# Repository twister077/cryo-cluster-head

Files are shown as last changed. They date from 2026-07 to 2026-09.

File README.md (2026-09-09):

# CryoClusterHead — Open-Source Cluster Headache Detection & Relief System

> **⚠ Experimental Research Project.** Not a certified medical product. Use at your own risk.

## Overview

Cluster headaches are among the most excruciatingly painful conditions known. This project explores an open-source hardware and software approach to **early detection of cluster headache flare-ups** using continuous skin temperature monitoring. 

By tracking rapid localized temperature changes ($\Delta T/\Delta t$) at the temple/neck area during the prodromal phase, our goal is to provide an early warning notification **minutes before peak pain hits**, allowing for timely intervention (such as cold therapy or medication).

---

## Current Focus & Development Tracks

The repository is structured into two main tracks:

### 🚀 Track A — Non-BLE Test Patch (Active Focus)
- **Hardware:** Miniature round PCB (`cryo-alert-patch/hardware/pcb/`) featuring **STM32L011** MCU + **TMP117** high-precision temperature sensor (B.Cu contact), CR1220 battery, piezo buzzer, LED, and tactile switch (`SW1`).
- **Firmware (`cryo-alert-patch/firmware-stm32/`)**: PlatformIO / STM32Cube HAL implementation featuring TMP117 I2C driver, ADC battery monitoring, alert state machine, and robust **$\Delta T/\Delta t$ flare-up detection** (validated with a host-side unit test suite).

### 📡 Track B — BLE & Companion Ecosystem (Planned / Later)
- **Hardware & Software:** nRF52832-based variants, `cryo-active-cooler/`, and `cryo-mobile-app/` (Flutter + Rust core).
- **Status:** Documented for future integration after Track A hardware testing and validation are completed.

---

## Community & Collaboration Welcome!

Building open-source medical/health hardware and embedded firmware is a massive undertaking for a single developer. **I cannot do this alone!** 

Whether you are an embedded firmware engineer, PCB designer (KiCad), mobile app developer, or a fellow cluster headache sufferer / researcher wanting to share insights — **your input, contributions, and feedback are immensely welcome.**

- **Open Issues & PRs:** Feel free to open issues or submit pull requests directly in this repository.
- **Discussions / Contact:** Reach out via GitHub issues or discussions to collaborate.

---

## Repository Structure

- `cryo-alert-patch/` — Hardware schematics, Gerber files, and firmware (`firmware-stm32/` for STM32 test track, `firmware-zephyr-ble/` for Zephyr/BLE).
- `cryo-mobile-app/` — Flutter companion app with Rust core for real-time $\Delta T/\Delta t$ analysis *(Track B)*.
- `cryo-active-cooler/` — Optional Peltier active cooling module concept *(Track B)*.
- `plan.md` — Detailed multi-phase project roadmap.

## License

- **Firmware:** MIT
- **Hardware:** CERN-OHL-S-2.0

---

## Contributors & AI Co-Developer

- **Twister077** — Project Initiator, Lead Concept & Hardware Architect.
- **Hermes Agent (Nous Research)** — AI Co-Developer & Engineering Assistant (assisted with KiCad schematic reconstruction, DRC/ERC validation, Gerber preparation, and STM32 PlatformIO firmware/testing).

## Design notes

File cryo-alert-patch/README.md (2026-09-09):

# Cryo Alert Patch

> Part of the [CryoClusterHead](../README.md) system — open-source cluster headache detection and relief.

**Temperature sensor patch for early detection of cluster headache flare-ups.**

This repo contains two hardware/firmware tracks:

---

## Track A — Non-BLE test patch (current, active)

A simplified, standalone test version of the patch with **no Bluetooth**. Used to validate the core hypothesis: *Can skin temperature monitoring reliably detect cluster headache prodromes?*

**Hardware:** STM32L011 MCU + TMP117 precision temperature sensor + piezo buzzer + LED + button (all on a 34mm round PCB).

### PCB Renders (Track A)

| Isometric View | Top View (Components) | Bottom View (Skin Contact / TMP117) |
|:---:|:---:|:---:|
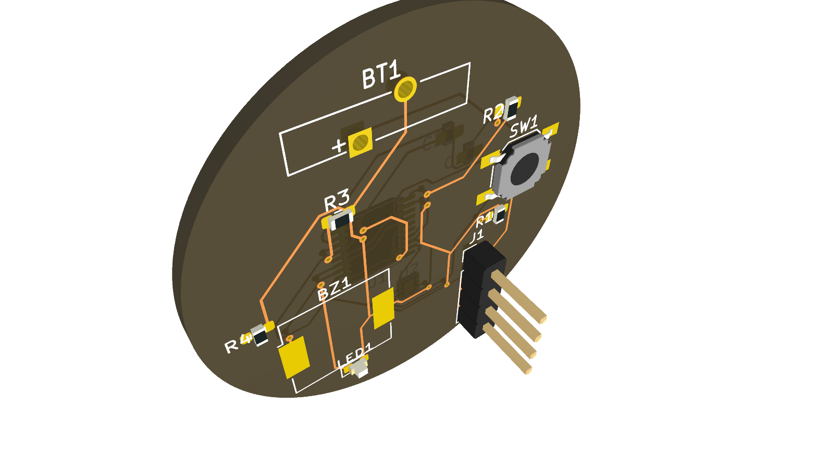
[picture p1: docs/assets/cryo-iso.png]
Isometric
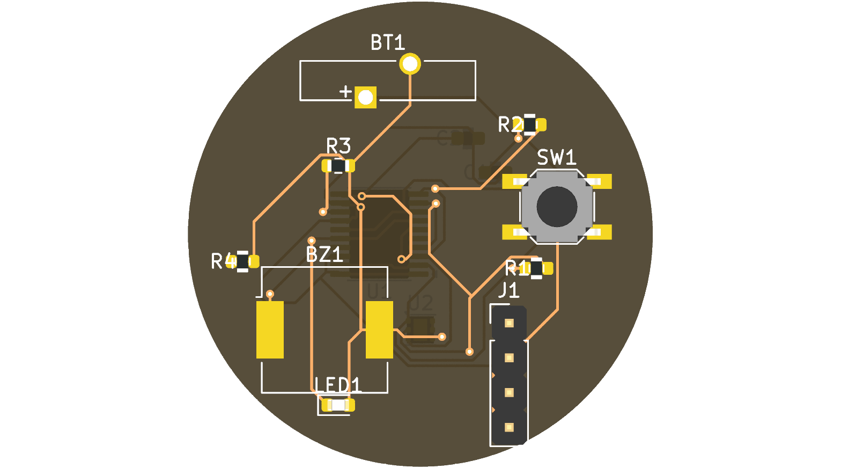
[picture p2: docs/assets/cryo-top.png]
Top
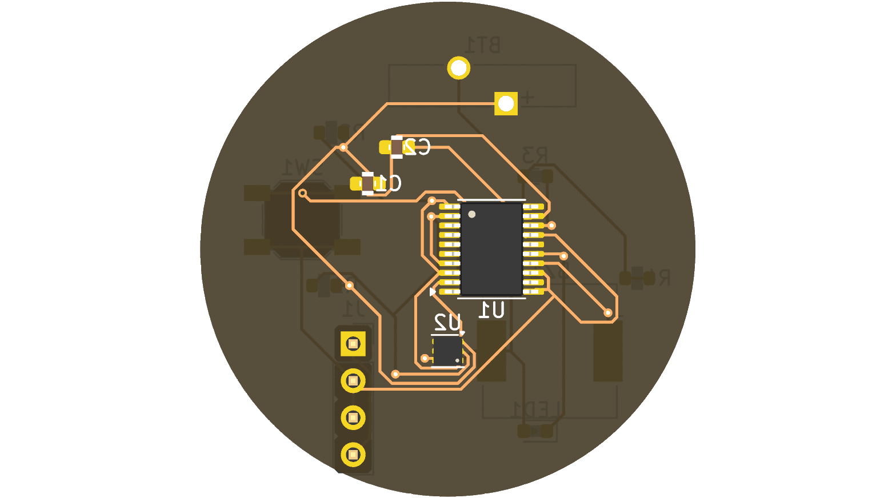
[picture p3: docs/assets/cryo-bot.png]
Bottom
|  |  |  |

**Firmware:** `firmware-stm32/` — PlatformIO + STM32Cube HAL.

| Feature | Status | Description |
|---|---|---|
| TMP117 I2C driver | ✅ | Reads skin temperature via sensor on B.Cu (direct skin contact) |
| ADC battery monitoring | ✅ | CR1220 voltage via VBAT_SENSE pin |
| dT/dt rate-of-change detection | ✅ | Rolling window, spike confirmed over consecutive high-rate samples |
| LED/buzzer alert state machine | ✅ | Normal / Warning / Critical / Muted states |
| Button debounce + snooze | ✅ | Press to silence alarm for 30 seconds |
| Low-power sleep | ✅ | Sleep mode (WFI) between measurements to extend battery life |
| Host-side unit tests | ✅ | 10/10 pass via `test/run_tests.sh` |
| BLE / phone connection | ⬜ | Not in scope for this track — see Track B |

### Quick start

```bash
cd firmware-stm32

# Run host-side unit tests (no hardware needed)
test/run_tests.sh

# Build firmware
pio run

# Flash via SWD (ST-Link / J-Link connected to J1 POGO pads)
pio run -t upload
```

See [`firmware-stm32/BUILD.md`](firmware-stm32/BUILD.md) for full build, flash, and pin mapping details.

---

## Track B — BLE version (planned, later phase)

The full Bluetooth Low Energy version with phone connectivity. This is the production target — the patch communicates with the [Cryo Mobile App](../cryo-mobile-app) for live dT/dt monitoring, push notifications, and data logging.

**Hardware:** nRF52832 MCU + MAX30205 clinical-grade temperature sensor.

**Firmware:** `firmware/` (Zephyr RTOS, Nordic SDK).

| Feature | Status | Description |
|---|---|---|
| BLE temperature broadcast | ⬜ | Advertise temperature via BLE advertising packets |
| MAX30205 sensor | ⬜ | Clinical-grade temperature sensing |
| Mobile app integration | ⬜ | Connect to Cryo Mobile App for live monitoring |
| Data logging | ⬜ | Store temperature history for later analysis |

> **Note:** The nRF52832 PCB design has known issues (pin mapping errors, missing crystal/antenna) that need to be resolved before Track B can be built. See the [project plan](../plan.md) for details.

---

## Components

| Component | Repository | Description |
|---|---|---|
| Alert Patch | `cryo-alert-patch` | This repo — firmware + hardware |
| Mobile App | `cryo-mobile-app` | Flutter + Rust Core — dT/dt detection |
| Active Cooler | `cryo-active-cooler` | Optional add-on — Peltier cooling module |

## License

- **Firmware:** MIT
- **Hardware:** CERN-OHL-S-2.0

> **⚠ Experimental device. Not a certified medical product. Use at your own risk.**

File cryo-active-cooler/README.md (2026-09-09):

# Cryo Active Cooler

> Part of the [CryoClusterHead](../README.md) system — open-source cluster headache detection and relief.

**Smart Peltier cooling module with triple-redundant temperature safety.**

An optional add-on for the CryoClusterHead system. When a flare-up is detected, this headband-mounted module provides active cooling directly to the painful area.

> **Note on Project Status:** This module (along with BLE features) belongs to **Track B (Future / BLE Version)**. The current active development track is **Track A (Non-BLE Test Patch)** using the STM32L011 + TMP117.

## Features

Unlike simple Peltier drivers, the Active Cooler is a safety-first intelligent module:

- **3 cooling levels** — automatically selected based on flare-up severity
- **Triple temp voting** — reads temperature from 3 independent sources for fail-safe operation
- **15-minute max timer** — hard limit prevents over-cooling
- **Auto step-down** — gradually reduces cooling as temperature normalizes
- **No phone required** — can read the Alert Patch directly via BLE *(Track B)*

## Temperature Safety Voting

```
┌──────────────────┐
│ Patch BLE        │──┐
│ (via phone relay)│  │
└──────────────────┘  │
                      ├──► Firmware majority vote
┌──────────────────┐  │    (≥2 agree → use that temp)
│ Patch BLE        │──┘
│ (direct)         │
└──────────────────┘
┌──────────────────┐
│ Local sensor     │
│ (MAX30205 on     │
│  cold side)      │
└──────────────────┘
```

If fewer than 2 sources agree → **safe shutdown** (Level 0).

## Cooling Levels

| Level | Condition | PWM | Description |
|---|---|-----|---|
| 0 | Normal temp / safety fault | 0% | Off |
| 1 | Mild rise (+0.3–0.8°C) | 33% | Gentle cooling |
| 2 | Moderate rise (+0.8–1.5°C) | 66% | Active cooling |
| 3 | Strong rise (>1.5°C) | 100% | Max cooling |

- Each level auto-advances based on current temperature
- Auto step-down as temp drops
- Hard cutoff after 15 minutes regardless of level

## Quick Start *(Track B - Planned)*

```bash
cd firmware
west init -l .
west update
west build -b nrf52832dk_nrf52832 .
west flash
```

## License

- **Firmware:** MIT
- **Hardware:** CERN-OHL-S-2.0

> **⚠ Experimental device. Not a certified medical product. Use at your own risk.**

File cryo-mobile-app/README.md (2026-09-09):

# Cryo Mobile App

> Part of the [CryoClusterHead](../README.md) system — open-source cluster headache detection and relief.

**Flutter + Rust app for real-time temperature monitoring and flare-up detection.**

Pairs with the [Cryo Alert Patch](../cryo-alert-patch) via BLE to detect rapid temperature spikes (dT/dt) characteristic of cluster headache attacks. Sends push notifications before the peak pain hits.

> **Note on Project Status:** The mobile application relies on BLE connectivity, which belongs to **Track B (Future / BLE Version)**. The current active hardware and firmware testing track is **Track A (Non-BLE Test Patch)** using the STM32L011 + TMP117.

## Standalone Value

This app works standalone with the Alert Patch — no cooling hardware required:

- **Real-time temperature** — live °C readout from the patch
- **Flare-up detection** — proprietary dT/dt algorithm catches rapid temperature rises
- **Push alerts** — notified during the prodromal phase, minutes before peak pain
- **24h history** — charts and statistics to identify patterns and triggers
- **No cloud** — all processing happens on-device via the Rust core engine

## Architecture

```
┌──────────────┐   BLE    ┌───────────────┐   FFI    ┌──────────────┐
│ Alert Patch  │─────────▶│  Rust Core     │─────────▶│  Flutter UI  │
│ (Track B BLE)│          │  - BLE parser  │          │  - Dashboard │
│              │          │  - dT/dt algo  │          │  - History   │
│              │          │  - Notification│          │  - Settings  │
└──────────────┘          └───────────────┘          └──────────────┘
```

## Quick Start *(Track B - BLE Integration)*

```bash
# Rust core
cd rust-core
cargo test
cargo build --release

# Flutter app
cd flutter
flutter pub get
flutter run
```

## Building for Android / iOS

```bash
# Build Rust for Android
cargo ndk -t arm64-v8a -o flutter/android/app/src/main/jniLibs build --release

# Build Rust for iOS
cargo lipo --release

# Build Flutter
cd flutter
flutter build apk --release    # Android
flutter build ios --release    # iOS
```

## License

MIT

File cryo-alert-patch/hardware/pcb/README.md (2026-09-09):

# Cryo Temp Alert PCB — v6

**Date:** 2026-09-08
**Status:** Production-ready (0 real DRC errors, 32 cosmetic warnings; ERC 0 errors)
**Validation:** KiCad DRC/ERC + MCP SVG render + netlist cross-check

## Specs
- Board: Ø34mm round (radius 17mm)
- Layers: 2 (F.Cu + B.Cu)
- Components: 13 footprints
  - **U1** STM32L011 MCU (TSSOP-20) — F.Cu at (-3, 0)
  - **U2** TMP117 temperature sensor (TMP117xxDRV, WSON-6-1EP) — **B.Cu** at (0, 7) ← skin contact
  - **BT1** CR1220 battery holder — F.Cu
  - **BZ1** Piezo buzzer — F.Cu
  - **LED1** SMD LED — F.Cu
  - **SW1** SKQG tactile switch — F.Cu
  - **J1** Pin header 1x4 (POGO programmer) — F.Cu
  - **R1, R2** 4.7k I2C pull-ups — F.Cu
  - **R3** 10k (NRST pull-up), **R4** LED current limiter — F.Cu
  - **C1, C2** 100nF decoupling — B.Cu near MCU
- Nets: 12 (GND, VCC, SDA, SCL, NRST, VBAT_SENSE, BUZZER, LED_SIG, SW_SIG, I2C_ADDR, VDDA, DEC_100NF)

## Temperature sensor: TMP117 (deliberate choice)
The board uses the **TMP117** (by TI) as the skin temperature sensor, deliberately instead of the
MAX30208 — among other reasons, because of the simpler wiring in this phase.

- **Schematic symbol:** `Sensor_Temperature:TMP117xxDRV` (value `TMP117xxDRV`)
- **PCB footprint:** `WSON-6-1EP_2x2mm_P0.65mm_EP1x1.6mm` on B.Cu
- Same I2C pinout as the MAX30208 (SCL/SDA/ADD0/ALERT/V+/GND), so it can later be
  swapped for the MAX30208 in the Bluetooth revision.

> **Future:** the next revision will get Bluetooth (nRF) and the MAX30208 sensor.
> For now both the schematic and PCB are configured for the TMP117.

## Schematic (rebuilt 2026-09-08)
The schematic was fully rebuilt so it renders correctly in the KiCad GUI:
- **Real root UUID** (was all-null `00000000-...` → blank GUI sheet)
- **Real net labels** (46 total) connect the pins electrically
- **ERC: 0 errors** (7 cosmetic warnings: spare GPIOs on power rails + VBAT_SENSE test point)
- Components on an A4 sheet with net labels instead of only physical wires

## Contents of this bundle (v6)
- `cryo-temp-alert.kicad_sch` — schematic (rebuilt, renders correctly)
- `cryo-temp-alert.kicad_pcb` — PCB (U2 = TMP117)
- `cryo-temp-alert.kicad_pro` — project file
- `cryo-temp-alert.kicad_prl` — layout
- `sym-lib-table` / `fp-lib-table` — library configuration
- `schematic.pdf` — schematic export (rebuilt)
- `gerbers/cryo-temp-alert-jlcpcb.zip` — JLCPCB fabrication bundle (fresh export)
- `renders/cryo-3d-renders.zip` — 3D renders
- `cryo-temp-alert-drc.rpt` — KiCad DRC report (32 cosmetic warnings, 0 errors)
- `README.md` — this file

## For JLCPCB fabrication
Upload `gerbers/cryo-temp-alert-jlcpcb.zip` to https://jlcpcb.com/quote.
Contains 7 Gerber layers + drill + job file.

## For manual assembly
1. **U2 (TMP117)** on the **bottom** (B.Cu, skin-contact side)
2. Remaining components on top (F.Cu)
3. Insert CR1220 battery into BT1
4. Program via J1 POGO pads (SWDIO/SWDCLK/RESET/GND)

## Layers / design notes
- Sensor on B.Cu for skin-temperature measurement
- Pad-to-mask clearance 0.05mm (0.65mm pitch)
- Minimum track width 0.2mm

Validated: 0 real DRC errors, 0 ERC errors, 0 unconnected pads.

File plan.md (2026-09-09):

# CryoClusterHead — Build & Validation Plan

> **Goal:** Validate the theory that cluster headache flare-ups can be detected via skin temperature (dT/dt), by building a working patch and testing it on a real patient.

## Background

Cluster headaches are among the most excruciatingly painful conditions known. This project explores an open-source hardware and software approach to **early detection of cluster headache flare-ups** using continuous skin temperature monitoring. By tracking rapid localized temperature changes (dT/dt) at the temple/neck area during the prodromal phase, our goal is to provide an early warning notification **minutes before peak pain hits**, allowing timely intervention (such as cold therapy or medication).

---

## Current Firmware Status (STM32L011 — `cryo-alert-patch/firmware-stm32/`)

> ✅ = Complete | 🚧 = In Progress | ⬜ = Not started

| Component | Status | Notes |
|---|---|---|
| TMP117 I2C driver | ✅ | `src/tmp117.c` — temperature sensor on B.Cu (skin contact) |
| ADC battery monitoring | ✅ | VBAT_SENSE on PA0, CR1220 voltage divider |
| dT/dt rate-of-change detection | ✅ | `src/dTdt.c` — rolling window, spike confirmation (3 consecutive high rates) |
| LED/buzzer alert state machine | ✅ | Normal/Warning/Critical/Muted states |
| Button debounce + snooze | ✅ | PB4 input with debounce, 30s mute |
| Low-power sleep | ✅ | `src/power.c` — Sleep mode (WFI) between measurements |
| Host-side unit tests | ✅ | 10/10 pass via `test/run_tests.sh` |
| Build & flash documentation | ✅ | `BUILD.md` — SWD flash via J1 POGO pads |

**Build stats:** RAM 14.6% (300 B), Flash 67.5% (11 KB)

---

## Phase 0 — Project fixes (code + docs)

Before building new features, the existing codebase gets maintenance:

**What:** | **Why:**
---------|--------
Fix CI workflows (`app/rust-core` → `cryo-mobile-app/rust-core`, etc.) | 3 of 6 workflows point to non-existent paths
`main.c` BLE advertisement stub | `update_ble_advertisement()` creates local array but never sends via BLE
Translate documentation to English | Repo documentation should be accessible to all contributors

**Status:** ✅ Documentation translated. Firmware built and validated.

---

## Phase 1 — Validate the current prototype board (STM32L011, TMP117)

The existing v6 PCB needs a thorough review before field testing:

- **Run DRC/ERC again** — confirm the routing was completed, not just the schematic
- **Verify pin assignments** against the STM32L011 datasheet (QFN-32) — ensure correct mapping for I2C, ADC, GPIO, and SWD pins
- **Check the battery positive terminal** — verify VBAT_SENSE routing and proper connection to the CR1220 battery
- **Confirm SWD header** — ensure SWDIO and SWCLK are correctly routed to the J1 POGO pads for flashing

### 1.2 Assemble a first test unit

- **Order PCBA** via JLCPCB (recommended for small SMD components)
- Identify any missing components (e.g., crystal for STM32, decoupling caps)
- Probe all power rails before powering on the MCU

### 1.3 Bench test with a logic analyzer / scope

- Verify **I2C communication** with the TMP117 temperature sensor
- Confirm **LED and buzzer** operation according to the alert state machine
- Measure the **actual power consumption** in low‑power sleep mode

---

## Phase 2 — dT/dt detection firmware

> ✅ Core algorithm complete (`src/dTdt.c`). Unit tests pass. Spike confirmation logic validated.

- ✅ Temperature sampling at 2s interval with rolling window
- ✅ Rate of change (dT/dt) computed on consecutive sample pairs
- ✅ Spike detection: ≥3 consecutive high-rate readings (configurable threshold)
- ✅ LED + buzzer alert on critical temperature or flare-up detection
- ⬜ BLE notification to phone app (requires BLE stack integration)

---

## Phase 3 — Mobile app: real-time monitoring

- Show **live temperature + dT/dt** on the dashboard
- **Push notification** on alert (local, and remote if needed)
- **History graph** so the patient can identify triggers
- Profile/export the logged data for later analysis

---

## Phase 4 — Field test (single user)

- Wear the patch during a **real cluster headache** (or during a few normal days)
- Log all temperature data + timestamps
- Compare with the **known attack timeline** (from the patient's log)
- Determine sensitivity/specificity of the alert (how many seconds before peak pain, how many false positives)

---

## Open questions / risks

- **Hypothesis validity:** It is not yet proven that cluster headache prodromes cause measurable skin temperature spikes
- **Sensor placement:** Temple vs. neck — which site gives the clearest signal?
- **Threshold tuning:** The 0.5°C/min threshold is a starting point; will need tuning based on real data
- **False positives:** Normal activities (touching the patch, going outdoors) may cause dT/dt spikes unrelated to headaches

## Priority / recommended order

1. ✅ Firmware algorithm complete — ready for hardware testing
2. Build & flash documentation done
3. Next: Assemble test unit (Phase 1.2) and bench test (Phase 1.3)
4. Then: BLE integration (Phase 2 BLE notification)
5. Then: Field test (Phase 4)

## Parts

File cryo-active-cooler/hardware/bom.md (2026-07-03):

# Active Cooler — Bill of Materials

| # | Part | Value / P/N | Qty | Cost |
|---|---|---|:---:|:----:|
| 1 | MCU | nRF52832 (QFN-48) | 1 | $5.00 |
| 2 | Temp Sensor | MAX30205 (local safety) | 1 | $3.50 |
| 3 | Peltier | TES1-04903 (30×30mm, 12V) | 1 | $8.00 |
| 4 | USB-PD Trigger | CH224K (SOP-8) | 1 | $1.50 |
| 5 | USB-C Receptacle | 16-pin SMD | 1 | $0.50 |
| 6 | MOSFET | IRLZ44N (N-channel) | 1 | $0.80 |
| 7 | Heatsink | 30×30mm aluminum | 1 | $3.00 |
| 8 | Fan | 30×30×10mm, 5V | 1 | $4.00 |
| 9 | Diode | 1N5819 (Schottky) | 1 | $0.20 |
| 10 | Capacitor | 100nF 0603 | 4 | $0.20 |
| 11 | Capacitor | 10µF 0603 | 2 | $0.30 |
| 12 | Resistor | 5.1kΩ 0603 (CC) | 2 | $0.10 |
| 13 | Resistor | 10kΩ 0603 | 3 | $0.15 |
| 14 | PCB | 2-layer, 40×30mm | 1 | $4.00 |
| 15 | Enclosure | PETG 3D-print | 1 | $1.50 |
| 16 | Headband | Elastic, velcro | 1 | $3.00 |
| 17 | USB-C Cable | 1.5m, USB-IF | 1 | $5.00 |

**Total: ~$40.75** (excluding power bank)

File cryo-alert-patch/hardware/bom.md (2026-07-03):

# Alert Patch — Bill of Materials

| # | Part | Value / P/N | Qty | Cost |
|---|---|---|:---:|:----:|
| 1 | MCU | nRF52832 (QFN-48) | 1 | $5.00 |
| 2 | Temp Sensor | MAX30205 (TDFN-8) | 1 | $3.50 |
| 3 | Battery | CR1220 (40 mAh) | 1 | $1.00 |
| 4 | Battery Holder | CR1220 SMD | 1 | $0.50 |
| 5 | Capacitor | 100nF 0603 | 2 | $0.10 |
| 6 | Capacitor | 10µF 0603 | 1 | $0.15 |
| 7 | Resistor | 10kΩ 0603 | 2 | $0.10 |
| 8 | PCB | 2-layer, 20×20mm | 1 | $2.00 |
| 9 | Enclosure | TPU 3D-print | 1 | $1.00 |
| 10 | Adhesive | CGM patch (×10) | 1 | $5.00 |

**Total: ~$18.35** (excl. setup fees, shipping & VAT)

---

## Production & Cost Indication (NL/Europe)

For initial prototyping and fabrication, the designs are optimized for ordering via **JLCPCB** (or similar PCB fabrication services like PCBWay). Because of the tiny SMD components (QFN-48 MCU and TDFN-8 temperature sensor), manual soldering is extremely difficult. We highly recommend ordering a **fully assembled PCB (PCBA)**.

### Option A: Fully Assembled by JLCPCB (Recommended)
JLCPCB manufactures the board and solders the components automatically. Indicative pricing for a minimum batch of **5 pieces** delivered to the Netherlands:

| Cost Item | Cost (approx. EUR) | Description |
|---|---|---|
| **PCB Fabrication** | €2.00 | 5 pieces of 20×20 mm 2-layer PCB |
| **SMT Assembly Setup & Stencil** | €15.00 | Stencil creation and machine calibration |
| **Components (5 boards)** | €42.00 | nRF52 MCU, MAX30205 sensor, passives, battery holder |
| **Extended Part Fees** | €5.50 | Loading fees for MCU and sensor |
| **Shipping (EuroPacket)** | €7.50 | Standard shipping with DDP/IOSS to NL |
| **BTW / VAT (21%)** | €15.00 | Paid at checkout via IOSS |
| **Total Price** | **~€85.00 - €95.00** | Approx. **€18.00 per assembled patch** |

> [!TIP]
> **Shipping to the Netherlands**: Select **EuroPacket (DDP/IOSS)** during checkout. This automatically handles Dutch VAT, meaning PostNL/DHL will deliver it directly to your doorstep without any custom delay or extra administration fees.

### Option B: Raw PCBs only (DIY)
If you have access to a reflow hot-plate or stencil oven and want to solder the components yourself:

- **5 Raw PCBs**: ~€2.00
- **Shipping & BTW**: ~€7.00
- **Total Price**: **~€9.00** (excl. component costs)

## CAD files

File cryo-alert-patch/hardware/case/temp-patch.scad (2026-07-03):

// Cryo Alert Patch — Temp Patch TPU Enclosure (32mm)
// 3D-print in TPU 95A, 0.12 mm layer height, no supports
// Design version for 20x20mm PCB and CR1220 battery

/* [Dimensions] */
// Overall outer diameter of the circular case (mm)
outer_diameter   = 32.0;
// Overall height of the assembled case (mm)
total_height     = 4.0;
// Wall thickness of the circular enclosure (mm)
wall_thickness   = 1.2;

/* [Case Split] */
// Height of the bottom case (mm)
bottom_h = 2.2;
// Height of the top case (mm)
top_h    = 1.8;

/* [Cavity & Tolerances] */
// Material thickness under the MCU recess (mm)
floor_thick = 0.3;
// General clearance tolerance for fit (mm)
clearance   = 0.3;

/* [PCB Components] */
// PCB X dimension (mm)
pcb_x       = 20.0;
// PCB Y dimension (mm)
pcb_y       = 20.0;
// PCB thickness (mm)
pcb_z       = 0.8;
// nRF52 MCU package size (mm)
mcu_xy      = 6.0;
// nRF52 MCU package height (mm)
mcu_z       = 0.8;
// MAX30205 sensor window dimensions [X, Y] (mm)
sensor_win  = [5.0, 4.0];

/* [Battery Holder (CR1220 SMD)] */
// Battery holder overall diameter (fits solder tabs and clip, e.g. Keystone 1056) (mm)
battery_holder_d = 16.0;
// Battery holder overall height above PCB (mm)
battery_holder_h = 2.5;
// Battery holder offset in Y direction (mm)
battery_y_offset = 5.0;

/* [Alignment Lip & Snap-Fit] */
// Alignment lip height (mm)
lip_h       = 0.5;
// Alignment lip width (mm)
lip_w       = 0.6;
// Protrusion of the snap-fit ridge (mm)
snap_ridge_h = 0.2;
// Section radius of the snap-fit groove (mm)
snap_groove_r = 0.25;

/* [Render Selection] */
// Choose which part to render
part_to_render = "assembly"; // [bottom:Bottom Case, top:Top Case, assembly:Assembly, exploded:Exploded Assembly, print:Print Layout (Side-by-Side)]

/* [Hidden] */
eps      = 0.01;
$fn      = 96;

// Inner diameter of the case walls
inner_d  = outer_diameter - 2 * wall_thickness;

// ─── HELPERS ────────────────────────────────────────────────────────

module ring(od, id, h) {
  difference() {
    cylinder(d = od, h = h);
    cylinder(d = id, h = h + eps);
  }
}

module torus(r_torus, r_section) {
  rotate_extrude()
    translate([r_torus, 0, 0])
      circle(r = r_section);
}

// ─── MODULES ────────────────────────────────────────────────────────

module bottom_case() {
  difference() {
    // Outer body
    cylinder(d = outer_diameter, h = bottom_h);

    // PCB pocket (square, from top face down to z = 1.0)
    // The pocket depth is bottom_h - 1.0 = 1.2 mm.
    // The center in Z is at (1.0 + bottom_h)/2 = 1.6 mm.
    // The height of the pocket is 1.2 mm + eps.
    translate([0, 0, (1.0 + bottom_h) / 2])
      cube([pcb_x + clearance, pcb_y + clearance, bottom_h - 1.0 + eps], center = true);

    // MCU recess (centered, from z = 0.3 to z = 1.0)
    // The height of the recess is 0.7 mm.
    // The center in Z is at (0.3 + 1.0)/2 = 0.65 mm.
    translate([0, 0, (floor_thick + 1.0) / 2])
      cube([mcu_xy + clearance, mcu_xy + clearance, 1.0 - floor_thick + eps], center = true);

    // Sensor window — through to skin side
    // Positioned at bottom edge of PCB area (Y offset is -6.5 mm)
    // Through-hole from z = -eps to z = 1.0 + eps
    sensor_y = -(pcb_y / 2 - sensor_win.y / 2 - 1.5);
    translate([0, sensor_y, 0.5])
      cube([sensor_win.x, sensor_win.y, 1.0 + 2 * eps], center = true);

    // Alignment step groove on top face (cut from z = bottom_h - lip_h to z = bottom_h)
    translate([0, 0, bottom_h - lip_h])
      ring(inner_d + 2 * lip_w, inner_d, lip_h + eps);

    // Snap groove inside the step vertical wall (cut at z = bottom_h - lip_h / 2)
    translate([0, 0, bottom_h - lip_h / 2])
      torus(r_torus = inner_d/2 + lip_w, r_section = snap_groove_r);
  }
}

module top_case() {
  union() {
    difference() {
      // Outer body
      cylinder(d = outer_diameter, h = top_h);

      // Hollow interior (above wall height)
      // depth is 0.6 mm, leaving 1.2 mm ceiling
      translate([0, 0, -eps])
        cylinder(d = inner_d, h = top_h - wall_thickness + eps);

      // Battery holder pocket (fits the SMD holder tabs and clip)
      // depth is battery_holder_h - (bottom_h - 1.0) + clearance = 1.6 mm, leaving 0.2 mm ceiling
      bat_holder_depth = battery_holder_h - (bottom_h - 1.0) + clearance;
      translate([0, battery_y_offset, -eps])
        cylinder(d = battery_holder_d + clearance, h = bat_holder_depth + eps);
    }

    // Alignment step lip (protrudes downward)
    // fits into the bottom case step groove
    // Goes from z = 0 down to z = -lip_h
    // Outer diameter is inner_d + 2 * lip_w - clearance = 30.5 mm
    // Inner diameter is inner_d = 29.6 mm
    translate([0, 0, -lip_h])
      ring(inner_d + 2 * lip_w - clearance, inner_d, lip_h);

    // Snap-fit ridge on the step vertical face (at z = -lip_h / 2)
    translate([0, 0, -lip_h / 2])
      torus(r_torus = inner_d/2 + lip_w - clearance/2, r_section = snap_ridge_h);
  }
}

module assembly() {
  bottom_case();
  translate([0, 0, bottom_h])
    top_case();
}

// ─── RENDER SELECTION ───────────────────────────────────────────────

if (part_to_render == "bottom") {
  bottom_case();
} else if (part_to_render == "top") {
  top_case();
} else if (part_to_render == "exploded") {
  // Exploded assembly view for visualization
  bottom_case();
  translate([0, 0, bottom_h + 15]) // Float the top case with a 15mm gap
    top_case();
} else if (part_to_render == "print") {
  // Side-by-side print layout
  // Bottom case sits flat on Z=0 at X = -18
  translate([-18, 0, 0])
    bottom_case();
  // Top case sits flat on Z=0 at X = 18 (rotated 180 degrees to lay its flat face down)
  translate([18, 0, top_h])
    rotate([180, 0, 0])
      top_case();
} else {
  assembly();
}

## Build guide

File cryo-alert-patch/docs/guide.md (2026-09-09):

# Cryo Alert Patch — Assembly & Usage (STM32 Non-BLE Track)

This guide is for the **current STM32L011-based non-Bluetooth test patch** (Track A).

## PCB Assembly & Flashing (Track A - STM32L011)

This track uses the STM32L011 microcontroller and the TMP117 temperature sensor. It does **NOT** use Bluetooth or the nRF52832.

1.  **Hardware:** Refer to `cryo-alert-patch/hardware/pcb/` for KiCad files, Gerbers, and schematics.
2.  **Firmware:** The source code is located in `cryo-alert-patch/firmware-stm32/`.

### Flashing Instructions (STM32L011 via SWD)

Connect a ST-Link debugger or similar SWD programmer to the **J1 POGO pin header** (Pinout: SWDIO, SWDCLK, RESET, GND).

Then, use **PlatformIO** to build and flash the firmware:

```bash
# Navigate to the firmware directory
cd cryo-alert-patch/firmware-stm32

# Build the firmware
pio run

# Flash the firmware to the board
pio run --target upload
```

## Future / BLE Track (Track B - nRF52832)

This track is **planned for a later revision** and will involve the nRF52832 microcontroller and BLE functionality. The current PCB design for Track A is not compatible with BLE components.

*   **Hardware:** See `cryo-alert-patch/hardware/pcb/README.md` for notes on the nRF52832 issues.
*   **Firmware:** Located in `cryo-alert-patch/firmware/` (Zephyr RTOS based).

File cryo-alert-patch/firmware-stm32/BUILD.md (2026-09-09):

# Cryo Temp Alert v6 — Build & Flash Instructions

## Prerequisites

- **PlatformIO CLI** (`pio`)
- **ST-Link** or **J-Link** debugger/programmer
- **SWD header** — POGO pads (J1) on the PCB: SWDIO, SWDCLK, RESET, GND

## Build

```bash
cd cryo-alert-patch/firmware-stm32
pio run
```

This compiles the firmware for the `nucleo_l011k4` target (STM32L011K4T6).
Output: `.pio/build/nucleo_l011k4/firmware.bin`

## Flash via ST-Link (SWD)

Connect your ST-Link (or Nucleo board) to the POGO pads on the PCB:

| POGO Pad | STM32 Pin | Debugger Wire |
|---|---|---|
| GND | GND | GND |
| SWDIO | PA13 | SWDIO |
| SWDCLK | PA14 | SWDCLK |
| RESET | NRST | NRST |

```bash
# Flash + reset
pio run --target upload

# Monitor serial output (if UART is connected)
pio device monitor
```

## Build & Run Tests (Host-side)

The dT/dt detection algorithm has host-side unit tests that run on your PC
(without hardware):

```bash
cd cryo-alert-patch/firmware-stm32
gcc -I src -o test/test_dtdt test/test_dtdt.c src/dTdt.c -lm
./test/test_dtdt
```

Expected output: `10 checks, 0 failures`

## Resource Usage

| Resource | Used | Total | Util |
|---|---|---|---|
| RAM | 300 B | 2048 B | 14.6% |
| Flash | 11 KB | 16 KB | 67.5% |

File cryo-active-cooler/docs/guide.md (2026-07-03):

# Active Cooler — Assembly & Safety

## PCB Assembly
1. Reflow nRF52832 + CH224K + passives.
2. Solder USB-C receptacle, IRLZ44N, 1N5819.
3. Solder local MAX30205 (position near cold side).
4. Attach Peltier to heatsink with thermal epoxy.
5. Wire fan to 5V header.

## First Test
1. Flash firmware: `west flash`
2. Connect USB-PD power bank — LED indicates PD negotiation.
3. Place near an active Alert Patch — verify BLE connection starts.
4. Warm the local sensor with finger — verify level transitions.

## Level Indicator
- **Level 0:** Fan off, Peltier off
- **Level 1:** Fan low, gentle cooling
- **Level 2:** Fan medium, active cooling
- **Level 3:** Fan max, full Peltier
- **Flashing LED:** Safety fault — check temp sources

## Safety Rules
- Hard cutoff at 15 minutes (regardless of level)
- Auto stop if temp drops below threshold
- Safe shutdown if <2 temperature sources agree
- Immediate stop if USB is unplugged (hardware kill)

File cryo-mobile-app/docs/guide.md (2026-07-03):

# Mobile App — Development Guide

## Rust Core

```bash
cd rust-core
cargo test          # Run unit tests
cargo clippy        # Lint
cargo build --release
```

## Flutter App

```bash
cd flutter
flutter pub get
flutter analyze
flutter run
```

## FFI Reference

| Function | Args | Returns | Description |
|---|---|---|---|
| `cryo_init` | window_size, threshold | 0 = ok | Initialize dT/dt detector |
| `cryo_process_temperature` | temp_c | alert_code | Feed sample, get alert |
| `cryo_reset` | — | 0 = ok | Clear detector state |

Alert codes: `0` = None, `1` = Warning (flare-up detected!), `2` = Critical

## BLE Protocol

The Alert Patch broadcasts temperature in BLE manufacturer data:

| Byte | Field |
|---|---|
| 0-1 | Manufacturer ID (0x0059) |
| 2-3 | Temperature (°C × 100) |
| 4 | Battery (mV / 10) |
| 5 | Sequence |
| 6 | Status |

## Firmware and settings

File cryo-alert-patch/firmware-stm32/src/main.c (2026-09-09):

#include "stm32l0xx_hal.h"
#include "tmp117.h"
#include "dTdt.h"
#include "power.h"

/* Pin mapping (matches KiCad v6 netlist) */
#define LED_PIN      GPIO_PIN_3   /* PB3 -> LED_SIG */
#define LED_PORT     GPIOB
#define BUZZER_PIN   GPIO_PIN_8   /* PA8 -> BUZZER */
#define BUZZER_PORT  GPIOA
#define BUTTON_PIN   GPIO_PIN_4   /* PB4 -> SW_SIG */
#define BUTTON_PORT  GPIOB
#define VBAT_PIN     GPIO_PIN_0   /* PA0 -> VBAT_SENSE (ADC) */
#define VBAT_PORT    GPIOA

/* Thresholds */
#define TEMP_HIGH_C   38.5f
#define TEMP_LOW_C    34.0f
#define TEMP_CRIT_HI  42.0f
#define TEMP_CRIT_LO  30.0f
#define VBAT_LOW      2.2f
#define DTDT_THRESHOLD 0.5f  /* °C/min rapid rise threshold for flare-up */

/* Timing (ms) */
#define MEASURE_PERIOD     2000
#define BLINK_NORMAL       2000
#define BLINK_WARNING      500
#define BLINK_ALERT        200
#define MUTE_DURATION      30000
#define DEBOUNCE           50

typedef enum {
    STATE_NORMAL = 0,
    STATE_WARNING,
    STATE_CRITICAL_ALERT,
    STATE_MUTED
} SystemState;

static SystemState state = STATE_NORMAL;
static uint32_t lastMeasure = 0;
static uint32_t lastBlink = 0;
static uint32_t muteStart = 0;
static uint8_t ledOn = 0;

static I2C_HandleTypeDef hi2c;
static ADC_HandleTypeDef hadc;
static TMP117_t sensor;
static dTdt_t dtdtTracker;

static void SystemClock_Config(void);
static void MX_GPIO_Init(void);
static void MX_I2C1_Init(void);
static void MX_ADC_Init(void);
static void Error_Handler(void);

int main(void) {
    HAL_Init();
    SystemClock_Config();
    MX_GPIO_Init();
    MX_I2C1_Init();
    MX_ADC_Init();
    Power_Init();
    dTdt_Init(&dtdtTracker);

    if (TMP117_Init(&sensor, &hi2c, TMP117_I2C_ADDR) != 0) {
        HAL_GPIO_WritePin(LED_PORT, LED_PIN, GPIO_PIN_SET);
    } else {
        TMP117_SetMode(&sensor, 0x00); /* continuous conversion */
    }

    while (1) {
        uint32_t now = HAL_GetTick();

        /* Button (mute/snooze) with debounce */
        if (HAL_GPIO_ReadPin(BUTTON_PORT, BUTTON_PIN) == GPIO_PIN_RESET) {
            HAL_Delay(DEBOUNCE);
            if (HAL_GPIO_ReadPin(BUTTON_PORT, BUTTON_PIN) == GPIO_PIN_RESET) {
                if (state == STATE_CRITICAL_ALERT || state == STATE_WARNING) {
                    state = STATE_MUTED;
                    muteStart = now;
                    HAL_GPIO_WritePin(BUZZER_PORT, BUZZER_PIN, GPIO_PIN_RESET);
                }
            }
        }

        if (state == STATE_MUTED && (now - muteStart) > MUTE_DURATION) {
            state = STATE_NORMAL;
        }

        /* Periodic measurement */
        if ((now - lastMeasure) >= MEASURE_PERIOD) {
            lastMeasure = now;

            float temp = 0;
            if (TMP117_ReadTempC(&sensor, &temp) != 0) {
                temp = 36.5f; /* fallback if read error */
            }

            /* Update dT/dt rate-of-change analysis */
            dTdt_Push(&dtdtTracker, temp);
            int flareUpDetected = dTdt_IsSpike(&dtdtTracker, DTDT_THRESHOLD);

            /* VBAT via ADC */
            HAL_ADC_Start(&hadc);
            HAL_ADC_PollForConversion(&hadc, 10);
            uint16_t adcRaw = HAL_ADC_GetValue(&hadc);
            HAL_ADC_Stop(&hadc);
            float vbat = (adcRaw * 3.0f / 4095.0f);

            if (state != STATE_MUTED) {
                if (temp < TEMP_CRIT_LO || temp > TEMP_CRIT_HI || vbat < VBAT_LOW || flareUpDetected) {
                    state = STATE_CRITICAL_ALERT;
                } else if (temp < TEMP_LOW_C || temp > TEMP_HIGH_C) {
                    state = STATE_WARNING;
                } else {
                    state = STATE_NORMAL;
                }
            }
        }

        /* Actuators */
        switch (state) {
            case STATE_NORMAL:
                if ((now - lastBlink) >= BLINK_NORMAL) {
                    lastBlink = now;
                    ledOn = !ledOn;
                    HAL_GPIO_WritePin(LED_PORT, LED_PIN, ledOn ? GPIO_PIN_SET : GPIO_PIN_RESET);
                }
                HAL_GPIO_WritePin(BUZZER_PORT, BUZZER_PIN, GPIO_PIN_RESET);
                break;

            case STATE_WARNING:
                if ((now - lastBlink) >= BLINK_WARNING) {
                    lastBlink = now;
                    ledOn = !ledOn;
                    HAL_GPIO_WritePin(LED_PORT, LED_PIN, ledOn ? GPIO_PIN_SET : GPIO_PIN_RESET);
                }
                HAL_GPIO_WritePin(BUZZER_PORT, BUZZER_PIN, GPIO_PIN_RESET);
                break;

            case STATE_CRITICAL_ALERT:
                if ((now - lastBlink) >= BLINK_ALERT) {
                    lastBlink = now;
                    ledOn = !ledOn;
                    HAL_GPIO_WritePin(LED_PORT, LED_PIN, ledOn ? GPIO_PIN_SET : GPIO_PIN_RESET);
                    HAL_GPIO_WritePin(BUZZER_PORT, BUZZER_PIN, ledOn ? GPIO_PIN_SET : GPIO_PIN_RESET);
                }
                break;

            case STATE_MUTED:
                HAL_GPIO_WritePin(LED_PORT, LED_PIN, GPIO_PIN_SET);
                HAL_GPIO_WritePin(BUZZER_PORT, BUZZER_PIN, GPIO_PIN_RESET);
                break;
        }

        /* Low-power sleep between iterations when not alarming */
        if (state == STATE_NORMAL) {
            Power_EnterSleepMode();
        }
    }
}

static void MX_I2C1_Init(void) {
    hi2c.Instance = I2C1;
    hi2c.Init.Timing = 0x2000090E; /* 100kHz */
    hi2c.Init.OwnAddress1 = 0;
    hi2c.Init.AddressingMode = I2C_ADDRESSINGMODE_7BIT;
    hi2c.Init.DualAddressMode = I2C_DUALADDRESS_DISABLE;
    hi2c.Init.GeneralCallMode = I2C_GENERALCALL_DISABLE;
    hi2c.Init.NoStretchMode = I2C_NOSTRETCH_DISABLE;
    if (HAL_I2C_Init(&hi2c) != HAL_OK) {
        Error_Handler();
    }
    if (HAL_I2CEx_ConfigAnalogFilter(&hi2c, I2C_ANALOGFILTER_ENABLE) != HAL_OK) {
        Error_Handler();
    }
    if (HAL_I2CEx_ConfigDigitalFilter(&hi2c, 0) != HAL_OK) {
        Error_Handler();
    }
}

static void MX_ADC_Init(void) {
    hadc.Instance = ADC1;
    hadc.Init.OversamplingMode = DISABLE;
    hadc.Init.ClockPrescaler = ADC_CLOCK_SYNC_PCLK_DIV4;
    hadc.Init.Resolution = ADC_RESOLUTION_12B;
    hadc.Init.DataAlign = ADC_DATAALIGN_RIGHT;
    hadc.Init.ScanConvMode = ADC_SCAN_DIRECTION_FORWARD;
    hadc.Init.EOCSelection = ADC_EOC_SINGLE_CONV;
    hadc.Init.LowPowerAutoWait = DISABLE;
    hadc.Init.LowPowerAutoPowerOff = DISABLE;
    hadc.Init.ContinuousConvMode = DISABLE;
    hadc.Init.DiscontinuousConvMode = DISABLE;
    hadc.Init.ExternalTrigConv = ADC_SOFTWARE_START;
    hadc.Init.SamplingTime = ADC_SAMPLETIME_7CYCLES_5;
    if (HAL_ADC_Init(&hadc) != HAL_OK) {
        Error_Handler();
    }
    ADC_ChannelConfTypeDef sConfig = {0};
    sConfig.Channel = ADC_CHANNEL_0; /* PA0 */
    sConfig.Rank = ADC_RANK_CHANNEL_NUMBER;
    if (HAL_ADC_ConfigChannel(&hadc, &sConfig) != HAL_OK) {
        Error_Handler();
    }
}

static void MX_GPIO_Init(void) {
    GPIO_InitTypeDef GPIO_InitStruct = {0};

    __HAL_RCC_GPIOA_CLK_ENABLE();
    __HAL_RCC_GPIOB_CLK_ENABLE();

    /* LED (PB3) output */
    HAL_GPIO_WritePin(GPIOB, GPIO_PIN_3, GPIO_PIN_RESET);
    GPIO_InitStruct.Pin = GPIO_PIN_3;
    GPIO_InitStruct.Mode = GPIO_MODE_OUTPUT_PP;
    GPIO_InitStruct.Pull = GPIO_NOPULL;
    GPIO_InitStruct.Speed = GPIO_SPEED_FREQ_LOW;
    HAL_GPIO_Init(GPIOB, &GPIO_InitStruct);

    /* Buzzer (PA8) output */
    HAL_GPIO_WritePin(GPIOA, GPIO_PIN_8, GPIO_PIN_RESET);
    GPIO_InitStruct.Pin = GPIO_PIN_8;
    HAL_GPIO_Init(GPIOA, &GPIO_InitStruct);

    /* Button (PB4) input pull-up */
    GPIO_InitStruct.Pin = GPIO_PIN_4;
    GPIO_InitStruct.Mode = GPIO_MODE_INPUT;
    GPIO_InitStruct.Pull = GPIO_PULLUP;
    HAL_GPIO_Init(GPIOB, &GPIO_InitStruct);

    /* VBAT sense (PA0) analog */
    GPIO_InitStruct.Pin = GPIO_PIN_0;
    GPIO_InitStruct.Mode = GPIO_MODE_ANALOG;
    GPIO_InitStruct.Pull = GPIO_NOPULL;
    HAL_GPIO_Init(GPIOA, &GPIO_InitStruct);
}

static void SystemClock_Config(void) {
    RCC_OscInitTypeDef RCC_OscInitStruct = {0};
    RCC_ClkInitTypeDef RCC_ClkInitStruct = {0};

    RCC_OscInitStruct.OscillatorType = RCC_OSCILLATORTYPE_HSI;
    RCC_OscInitStruct.HSIState = RCC_HSI_ON;
    RCC_OscInitStruct.HSICalibrationValue = RCC_HSICALIBRATION_DEFAULT;
    RCC_OscInitStruct.PLL.PLLState = RCC_PLL_NONE;
    if (HAL_RCC_OscConfig(&RCC_OscInitStruct) != HAL_OK) {
        Error_Handler();
    }

    RCC_ClkInitStruct.ClockType = RCC_CLOCKTYPE_HCLK | RCC_CLOCKTYPE_SYSCLK | RCC_CLOCKTYPE_PCLK1;
    RCC_ClkInitStruct.SYSCLKSource = RCC_SYSCLKSOURCE_HSI;
    RCC_ClkInitStruct.AHBCLKDivider = RCC_SYSCLK_DIV1;
    RCC_ClkInitStruct.APB1CLKDivider = RCC_HCLK_DIV1;
    if (HAL_RCC_ClockConfig(&RCC_ClkInitStruct, FLASH_LATENCY_0) != HAL_OK) {
        Error_Handler();
    }
}

static void Error_Handler(void) {
    __disable_irq();
    while (1) {
    }
}

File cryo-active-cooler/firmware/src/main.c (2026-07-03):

#include <zephyr/kernel.h>
#include <zephyr/drivers/i2c.h>
#include <zephyr/bluetooth/bluetooth.h>
#include <zephyr/logging/log.h>

#include "levels.h"
#include "temp_voter.h"
#include "peltier.h"
#include "safety.h"
#include "auto_mode.h"
#include "ble_patch.h"
#include "ble_phone.h"

LOG_MODULE_REGISTER(main, CONFIG_LOG_DEFAULT_LEVEL);

static const struct device *local_i2c;
static int current_mode = MODE_OFF;
static bool cooling_active = false;

#define LOCAL_SENSOR_ADDR 0x48

#define CONTROL_INTERVAL_MS 5000

static int read_local_temp(float *temp)
{
    uint8_t buf[2];
    int ret = i2c_reg_read_byte(local_i2c, LOCAL_SENSOR_ADDR, 0x00, &buf[0]);
    if (ret) return ret;
    ret = i2c_reg_read_byte(local_i2c, LOCAL_SENSOR_ADDR, 0x01, &buf[1]);
    if (ret) return ret;

    uint16_t raw = ((uint16_t)buf[0] << 8) | buf[1];
    raw >>= 3;
    *temp = raw * 0.03125f;
    return 0;
}

static void refresh_temp_sources(void)
{
    float t;

    if (ble_patch_get_temp(&t) == 0) {
        temp_voter_feed(TEMP_SOURCE_PATCH_BLE, t);
    }

    if (ble_phone_get_temp(&t) == 0) {
        temp_voter_feed(TEMP_SOURCE_PHONE_RELAY, t);
    }

    if (read_local_temp(&t) == 0) {
        temp_voter_feed(TEMP_SOURCE_LOCAL, t);
    }
}

static void update_cooling(void)
{
    struct temp_vote_result vote = temp_voter_get_vote();
    int phone_mode = ble_phone_get_mode();

    if (!vote.safe) {
        LOG_WRN("No temp quorum — safe shutdown");
        peltier_off();
        cooling_active = false;
        current_mode = MODE_OFF;
        return;
    }

    if (safety_is_faulted()) {
        LOG_WRN("Safety fault: %s", safety_get_fault_reason());
        peltier_off();
        cooling_active = false;
        current_mode = MODE_OFF;
        return;
    }

    switch (phone_mode) {
    case MODE_OFF:
        if (cooling_active) {
            LOG_INF("Mode: off — stopping");
            peltier_off();
            cooling_active = false;
        }
        current_mode = MODE_OFF;
        break;

    case MODE_L1:
        if (!cooling_active) {
            LOG_INF("Mode: level 1 — start");
            safety_reset_timer();
            cooling_active = true;
        }
        peltier_set_level(MODE_L1);
        current_mode = MODE_L1;
        break;

    case MODE_L2:
        if (!cooling_active) {
            LOG_INF("Mode: level 2 — start");
            safety_reset_timer();
            cooling_active = true;
        }
        peltier_set_level(MODE_L2);
        current_mode = MODE_L2;
        break;

    case MODE_L3:
        if (!cooling_active) {
            LOG_INF("Mode: level 3 — start");
            safety_reset_timer();
            cooling_active = true;
        }
        peltier_set_level(MODE_L3);
        current_mode = MODE_L3;
        break;

    case MODE_AUTO: {
        int target = ble_phone_get_target_temp();
        auto_mode_set_target((float)target);
        bool should_cool = auto_mode_tick(vote.temperature);

        if (should_cool) {
            if (!cooling_active) {
                LOG_INF("Auto mode: cooling to %d°C (current: %.1f°C)",
                        target, vote.temperature);
                safety_reset_timer();
                cooling_active = true;
            }
            peltier_set_level(MODE_L3);
        } else {
            if (cooling_active) {
                LOG_INF("Auto mode: target reached — stopping");
                peltier_off();
                cooling_active = false;
            }
        }
        current_mode = MODE_AUTO;
        break;
    }

    default:
        peltier_off();
        cooling_active = false;
        current_mode = MODE_OFF;
        break;
    }
}

void main(void)
{
    int err;

    local_i2c = DEVICE_DT_GET(DT_NODELABEL(i2c1));
    if (!device_is_ready(local_i2c)) {
        LOG_ERR("Local I2C not ready");
        return;
    }

    err = bt_enable(NULL);
    if (err) {
        LOG_ERR("BLE init failed: %d", err);
        return;
    }

    temp_voter_init();
    peltier_init();
    safety_init();
    auto_mode_init();
    ble_patch_init();
    ble_phone_init();

    LOG_INF("Active Cooler started — 5 modes (Off/1/2/3/Auto)");

    while (1) {
        refresh_temp_sources();
        safety_tick();
        update_cooling();
        k_sleep(K_MSEC(CONTROL_INTERVAL_MS));
    }
}

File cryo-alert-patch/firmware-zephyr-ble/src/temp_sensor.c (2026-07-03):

#include <zephyr/kernel.h>
#include <zephyr/drivers/i2c.h>

#include "temp_sensor.h"

int temp_sensor_init(const struct device *i2c_dev)
{
    uint8_t cfg = 0x00;
    return i2c_reg_write_byte(i2c_dev, MAX30205_ADDR, MAX30205_REG_CFG, cfg);
}

int temp_sensor_read(const struct device *i2c_dev, float *temp)
{
    uint8_t buf[2];
    int ret = i2c_reg_read_byte(i2c_dev, MAX30205_ADDR, MAX30205_REG_TEMP, &buf[0]);
    if (ret) {
        return ret;
    }

    ret = i2c_reg_read_byte(i2c_dev, MAX30205_ADDR, MAX30205_REG_TEMP + 1, &buf[1]);
    if (ret) {
        return ret;
    }

    uint16_t raw = ((uint16_t)buf[0] << 8) | buf[1];
    raw >>= 3;
    *temp = raw * 0.03125f;

    return 0;
}

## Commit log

2026-09-09 Update cryo-alert-patch hardware (v6 production-ready PCB & documentation for cluster headache early detection hypothesis)
    [cryo-temp-alert-B_Courtyard.gbr, cryo-temp-alert-B_Cu.gbl, cryo-temp-alert-B_Fab.gbr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]
2026-09-09 Add STM32L0 HAL firmware with TMP117 driver, ADC battery monitoring, buzzer/LED alert state machine, and tactile switch mute button
    [cryo-temp-alert-B_Courtyard.gbr, cryo-temp-alert-B_Cu.gbl, cryo-temp-alert-B_Fab.gbr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]
2026-09-09 Restructure repo: remove top-level PCB duplicates and build artifacts, add STM32 firmware under cryo-alert-patch/firmware-stm32
    [cryo-temp-alert-B_Courtyard.gbr, cryo-temp-alert-B_Cu.gbl, cryo-temp-alert-B_Fab.gbr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]
2026-09-09 Remove duplicate top-level firmware dir (now under cryo-alert-patch/firmware-stm32)
2026-09-09 Translate Dutch documentation to English (plan.md, cryo-alert-patch/hardware/pcb/README.md)
2026-09-09 Add dT/dt rate-of-change detection module for cluster headache flare-up prediction and clean up firmware-stm32
2026-09-09 Add dT/dt flare-up detection, low-power sleep mode, and cleanup firmware-stm32
    - dTdt module: rolling window rate-of-change with spike confirmation (3 consecutive high reads)
    - power module: STM32L011 Sleep mode between measurements (WFI via SysTick wakeup)
    - .gitignore for firmware build artifacts
    - Integrated: TMP117 sensor → dT/dt analysis → LED/buzzer alert state machine
    - Build: SUCCESS (RAM 14.6%, Flash 67.7%)
    [dTdt.c, main.c]
2026-09-09 Remove unused Power_EnterStopMode dead code, fix SleepOnExit toggling in low-power sleep
2026-09-09 Fix dT/dt spike detection, add host-side unit tests (10 checks pass)
    - Spike rate now computed on the latest 2 consecutive samples (delta last 2s),
    not the full window, so flare-up onset is detected promptly
    - 10 host-side unit tests compile real src/dTdt.c against real header:
    init, steady-state (no spike), rapid rise (spike), rapid cold drop (spike),
    slow drift below threshold (no spike), single blip (no spike)
    - Build: SUCCESS (RAM 14.6%, Flash 67.5%)
    [dTdt.c, test_dtdt.c]
2026-09-09 Add test runner script, update plan.md with current firmware status
    - test/run_tests.sh: one-command build+run for host-side dT/dt unit tests
    - plan.md: comprehensive status table showing all firmware components,
    roadmap progress, open questions, and recommended next steps
2026-09-09 Clarify README: distinguish non-BLE test track (active) from BLE version (planned)
2026-09-09 Add root .gitignore, remove compiled test binary from git, and update guide.md for STM32 non-BLE test track
2026-09-09 Clarify Track B (BLE) status in Active Cooler and Mobile App READMEs
2026-09-09 Clarify Track A and Track B on the top-level README
2026-09-09 Update plan.md Phase 1 from nRF52832 to STM32L011 + TMP117 non-BLE test track
2026-09-09 Add PCB 3D renders to Track A section of cryo-alert-patch README
2026-09-09 Replace incorrect PCB renders with new generated images and update README
2026-09-09 Update assets with freshly rendered PCB views (top, bottom, isometric)
